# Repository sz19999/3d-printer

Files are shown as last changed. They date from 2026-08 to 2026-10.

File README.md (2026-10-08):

# EE Bachelor's Capstone Project - Cartesian 3D Printer

## Project Overview
This project involves the ground-up design and programming of a custom Cartesian 3D printer. Focuses on developing a hardware and software ecosystem — spanning from custom PCB design to a custom firmware.

## Core Objectives
*   **Mechanical Systems:** Design and assemble a rigid Cartesian frame optimized for precise XYZ axis motion control.
*   **Hardware Design:** Architect and route a custom mainboard Printed Circuit Board (PCB) from scratch, managing power distribution, stepper driver interfaces, and sensor inputs.
*   **Firmware Development:** Write dedicated, low-latency control firmware to handle G-code parsing, thermal regulation (PID loops), and precise motor acceleration profiles.

## Documents
*    **[HW & SW Architecture Diagram](./docs/assets/)** - Architectural block diagrams
*    **[PCB Schematics & Layout](./docs/)**

## Technical Stack & Tools
*   **Hardware / PCB Design:** Altium Designer
*   **Firmware Framework:** ESP-IDF, C

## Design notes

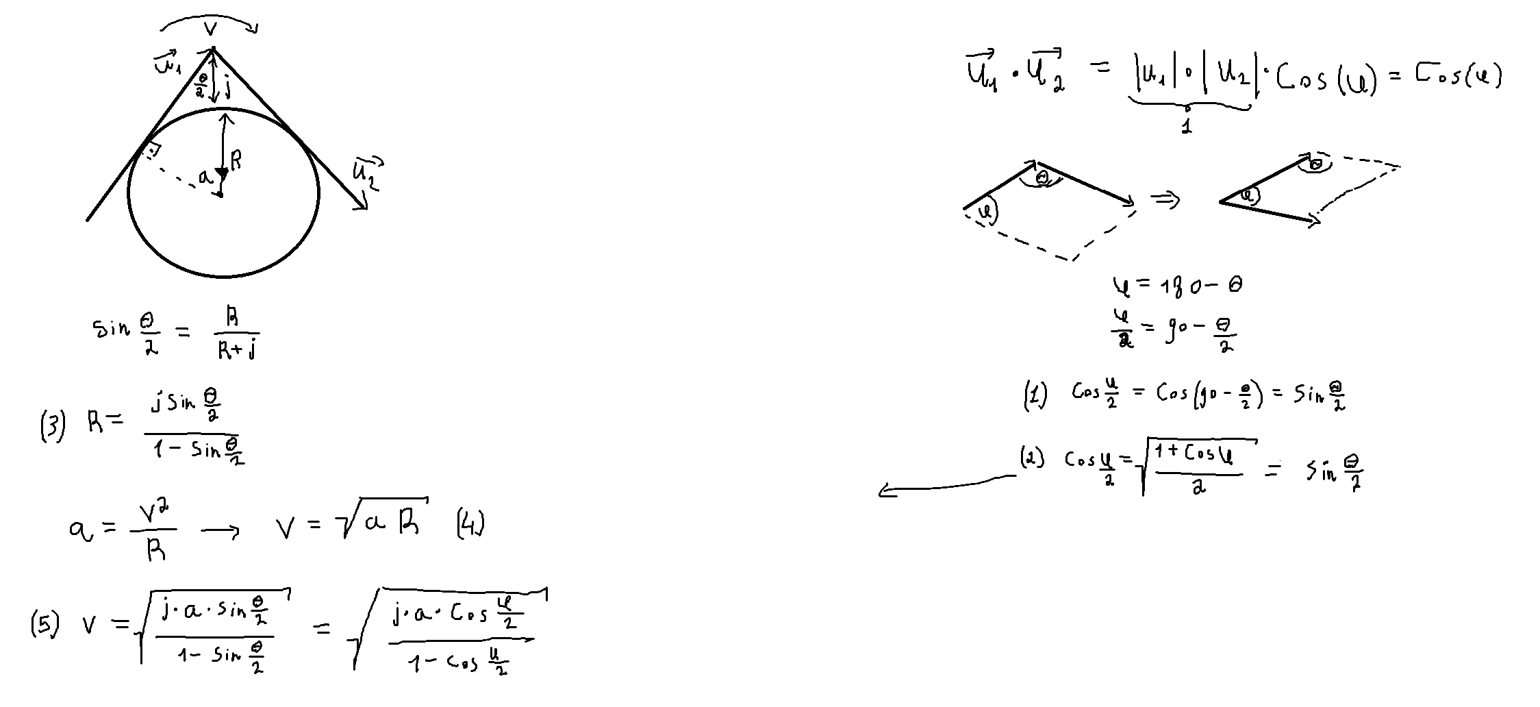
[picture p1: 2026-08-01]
docs/assets/junction_speed.png

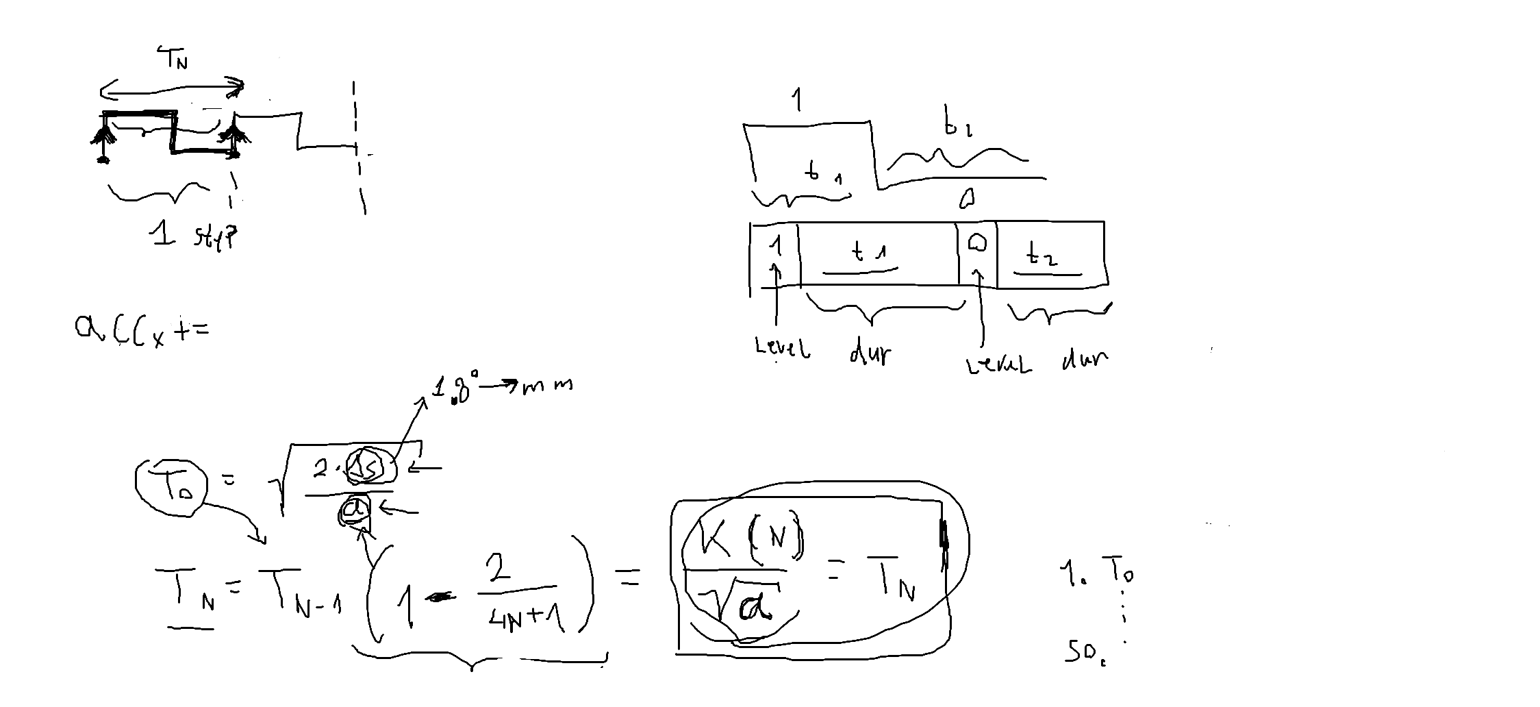
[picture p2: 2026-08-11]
docs/assets/cruise_speed.png

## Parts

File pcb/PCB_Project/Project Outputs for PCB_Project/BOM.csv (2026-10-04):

Line # | Name | Description | Designator | Quantity | SupplierPart | Supplier
 | sh-xh2.54-2p | Pins Structure:1x2P Pitch:2.5mm Mounting Type:Through Hole Number of Pins:2P Number of Rows:1 Number of PINs Per Row:2 Current Rating:3A Contact Material:Brass Contact Plating:Tin Operating Temperature:-25?~+85? Operating Temperature:-25?~+85? Voltage Rat | BED_ADC, BED_PWM, FAN, FAN_PWM, HEAD_ADC | 5 | C53261323 | LCSC
 | wj127-5.0-02p-14-00a | Number of Positions or Pins:1x2P Pitch:5mm Color:Green Mounting Type:Through Hole Number of Pins:2P Number of Rows:1 Number of PINs Per Row:2 Screw Specification:M2.5 Current Rating:15A Voltage Rating (Max):250V Wire Gauge - AWG:14~26 Wire Gauge - mm2:1.5 | BED_PWR, BTN_CN1, BTN_CN2, HEAD_PWR, PWR_DB1, PWR_DB2 | 6 | C3703 | LCSC
 | 100uF | Capacitance:100uF Tolerance:±20% Tolerance:±20% Voltage Rating:50V Ripple Current:146mA@120Hz Equivalent Series Resistance(ESR):- Diameter:8mm Height - Seated (Max):10.2mm Lifetime:2800hrs@105? Operating Temperature:-55?~+105? Operating Temperature:-55?~+ | C1, C2, C3, C4 | 4 | C970687 | LCSC
 | 100nF | Capacitance:100nF Tolerance:±10% Tolerance:±10% Voltage Rating:50V Temperature Coefficient:X7R | C5, C6, C7 | 3 | C1711 | LCSC
 | 22uF | Capacitance:22uF Tolerance:±20% Tolerance:±20% Voltage Rating:10V Temperature Coefficient:X5R | C8, C9, C10 | 3 | C29277 | LCSC
 | sh-xh2.54-4p | Pins Structure:1x4P Pitch:2.5mm Mounting Type:Through Hole Number of Pins:4P Number of Rows:1 Number of PINs Per Row:4 Current Rating:3A Contact Material:Brass Contact Plating:Tin Operating Temperature:-25?~+85? Operating Temperature:-25?~+85? Voltage Rat | CN2, CN3, CN4, CN5 | 4 | C53261325 | LCSC
 | s3mb-13-f | Diode Configuration:1 Independent Voltage - Forward(Vf@If):1.15V@3A Voltage - DC Reverse(Vr):1kV Current - Rectified:3A Reverse Leakage Current (Ir):10uA@1kV Non-Repetitive Peak Forward Surge Current:- Operating Junction Temperature Range:-65?~+150? Opera | D1 | 1 | C70426 | LCSC
 | wj127-5.0-04p-14-00a | Number of Positions or Pins:1x4P Pitch:5mm Color:Green Mounting Type:Through Hole Number of Pins:4P Number of Rows:1 Number of PINs Per Row:4 Screw Specification:M2.5 Current Rating:15A Voltage Rating (Max):250V Wire Gauge - AWG:14~26 Wire Gauge - mm2:1.5 | I2C_1, I2C_2 | 2 | C192779 | LCSC
 | 2.54-1*1p? | Pin Structure:1x1P Pitch:- Row Spacing:- Circluar Pins/Square Pins:Pin Header Mounting Type:Through Hole Number of Rows:1 Number of Pins:1P Current Rating:3A Voltage Rating (Max):- Length of Mating Pin:6mm Insulation Height:2.5mm Length of End Connection | J1, J2, J3, J4, J5, J6 | 6 | C81276 | LCSC
 | 2.54-1*3p? | Pin Structure:1x3P Pitch:2.54mm Row Spacing:- Circluar Pins/Square Pins:Pin Header Mounting Type:Through Hole Number of Rows:1 Number of Pins:3P Current Rating:3A Voltage Rating (Max):- Length of Mating Pin:6mm Insulation Height:2.5mm Length of End Connec | J7, J8, J9 | 3 | C49257 | LCSC
 | ncd0805r1_c84256 | Lamp Holder Type:- Illumination Color:Red Voltage - Forward(Vf):1.6V~2.6V Voltage - Forward(Vf):1.6V~2.6V Power(Watts):65mW Test Current:25mA Wavelength - Dominant:615nm~630nm Wavelength - Dominant:615nm~630nm Peak Wavelength:630nm Peak Wavelength:630nm D | LED1 | 1 | C84256 | LCSC
 | fh2.54-09-22pzd | Holes Structure:1x22P Pitch:2.54mm Circular Hole / Square Hole:Square Hole Mounting Type:Through Hole Number of Rows:1 Number of Positions:22P Current Rating:3A Holes Direction:Top Insulation Height:8.5mm Contact Material:Brass Contact Plating:Gold Operat | P1, P2 | 2 | C7500786 | LCSC
 | 2.54-1*8p??? | Holes Structure:1x8P Pitch:2.54mm Row Spacing:- Circular Hole / Square Hole:Square Hole Mounting Type:Through Hole Number of Rows:1 Number of Positions:8P Current Rating:3A Holes Direction:Top Insulation Height:8.5mm Contact Material:Brass Contact Plating | P3, P4, P5, P6, P8, P9, P10, P11 | 8 | C27438 | LCSC
 | 2.54-1*6p | Holes Structure:1x6P Pitch:2.54mm Row Spacing:- Circular Hole / Square Hole:Square Hole Mounting Type:Through Hole Number of Rows:1 Number of Positions:6P Current Rating:3A Voltage Rating (Max):- Holes Direction:Top Insulation Height:8.5mm Contact Materia | P7 | 1 | C40877 | LCSC
 | 2.54-1*4P |  | P18 | 1 | C2718488 | LCSC
 | dbt30s-7.62-2p-bk-p | Barrier Type:2-Side Pitch:7.62mm Number of Positions or Pins:1x2P Mounting Type:Straight Pin Location:Side Mount Number of Pins:2P Number of Rows:1 Number of PINs Per Row:2 Current Rating:15A Voltage Rating (Max):300V Wire Gauge - AWG:14~22 Wire Gauge - m | PWR1, PWR2 | 2 | C918082 | LCSC
 | ktc3265(range:160-320) | type:NPN Current - Collector(Ic):800mA Collector - Emitter Voltage VCEO:30V Pd - Power Dissipation:200mW DC Current Gain:160 DC Current Gain:160 Transition frequency(fT):120MHz Current - Collector Cutoff:100nA Vce Saturation(VCE(sat)):500mV Operating Temp | Q1, Q2 | 2 | C8531 | LCSC
 | 4.7k | Type:Thick Film Resistors Resistance:4.7kO Tolerance:±1% Tolerance:±1% Power(Watts): Overload Voltage (Max): Temperature Coefficient:±100ppm/? Temperature Coefficient:±100ppm/? Operating Temperature Range:-55?~+155? Operating Temperature Range:-55?~+155? | R1, R2, R3, R4, R5, R6, R9 | 7 | C17673 | LCSC
 | 1k | Type:Thick Film Resistors Resistance:1kO Tolerance:±1% Tolerance:±1% Power(Watts): Overload Voltage (Max): Temperature Coefficient:±100ppm/? Temperature Coefficient:±100ppm/? Operating Temperature Range:-55?~+155? Operating Temperature Range:-55?~+155? | R7, R8, R10, R11, R12 | 5 | C17513 | LCSC
 | 220 | Type:Thick Film Resistor Resistance:220O Tolerance:±1% Tolerance:±1% Power(Watts):125mW Voltage-Supply(Max):150V Temperature Coefficient:±100ppm/? Temperature Coefficient:±100ppm/? Operating Temperature:-55?~+155? Operating Temperature:-55?~+155? | R13 | 1 | C17557 | LCSC
 | ts6685h-250gf | Circuit:SPST Actuator Style:Round Button Operating Force:2.5N Mounting Type:Through Hole Length:6mm Width:6mm Switch Height:8.5mm Contact Current:50mA Voltage Rating:12V With Lamp:- Life:- | SW1 | 1 | C13828 | LCSC

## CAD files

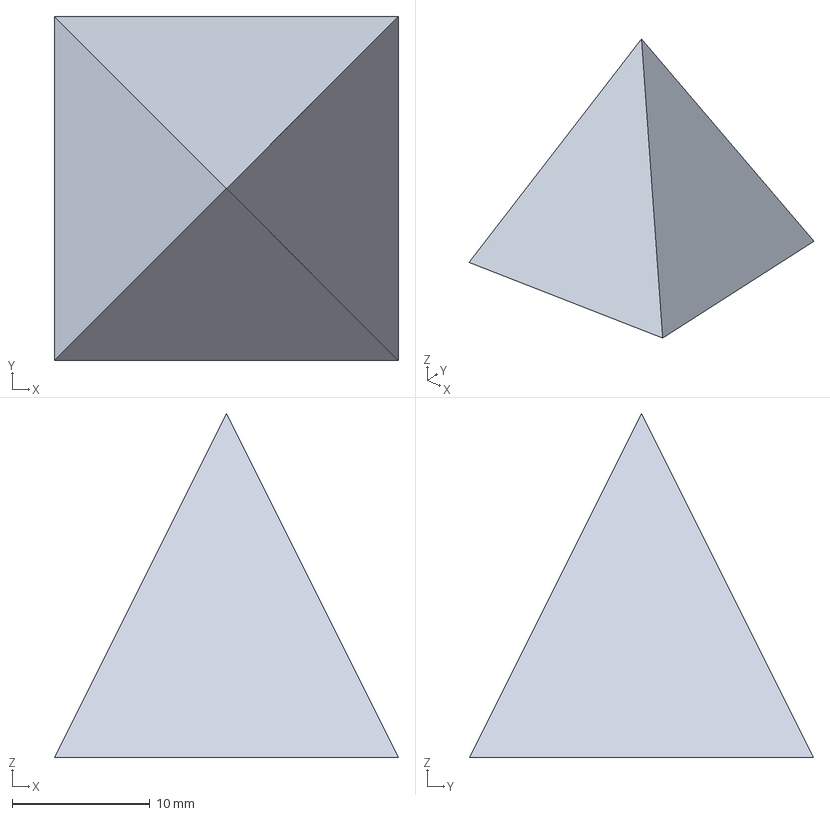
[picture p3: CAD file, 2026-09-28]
slicer/pyramid.3mf
25.0 x 25.0 x 25.0 mm

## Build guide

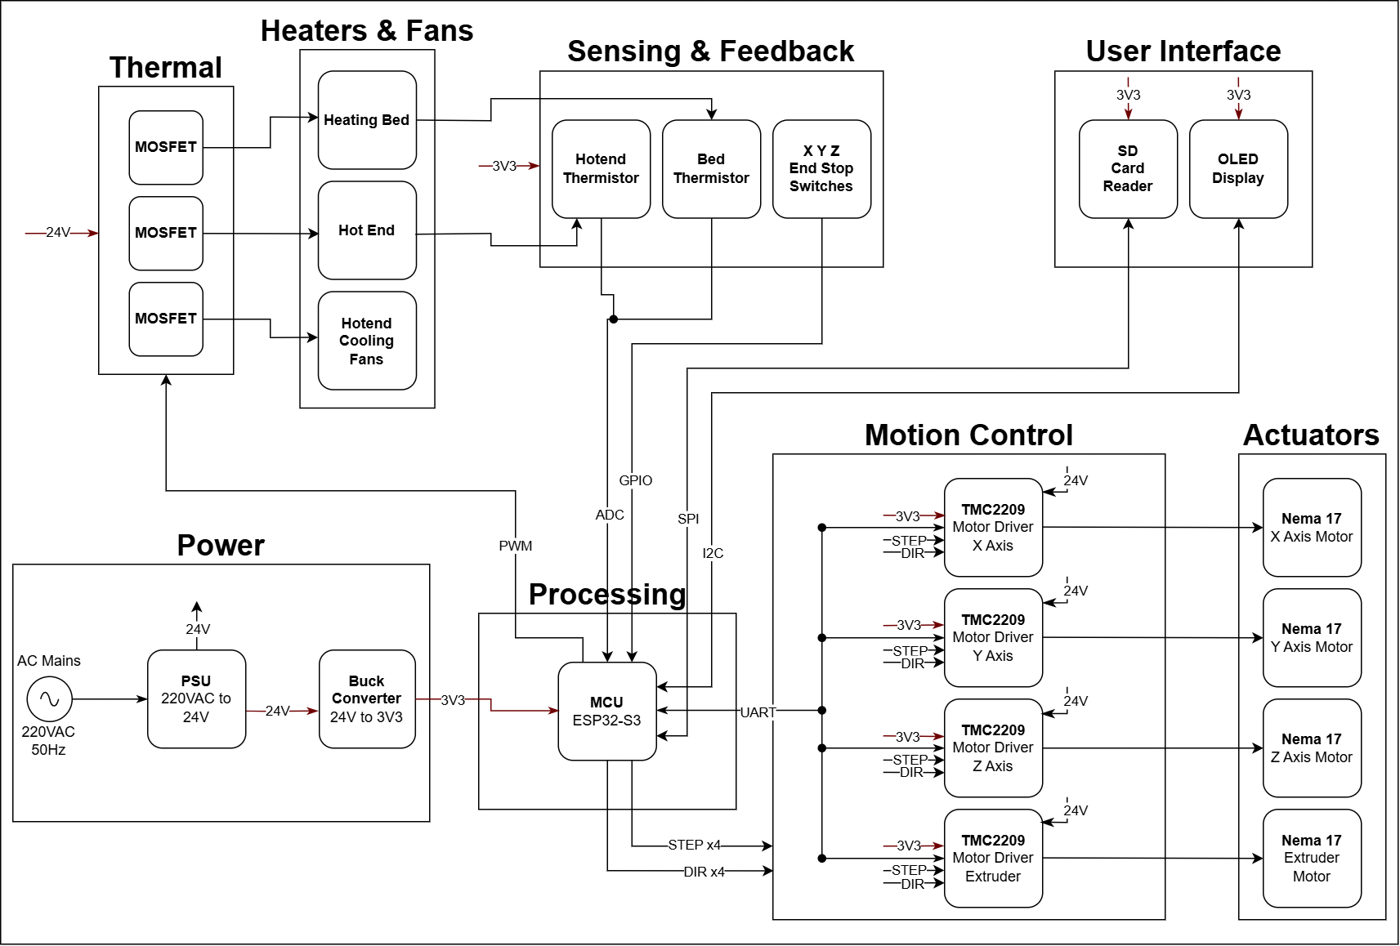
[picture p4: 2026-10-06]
docs/assets/3D Printer Hardware Architecture.drawio.png

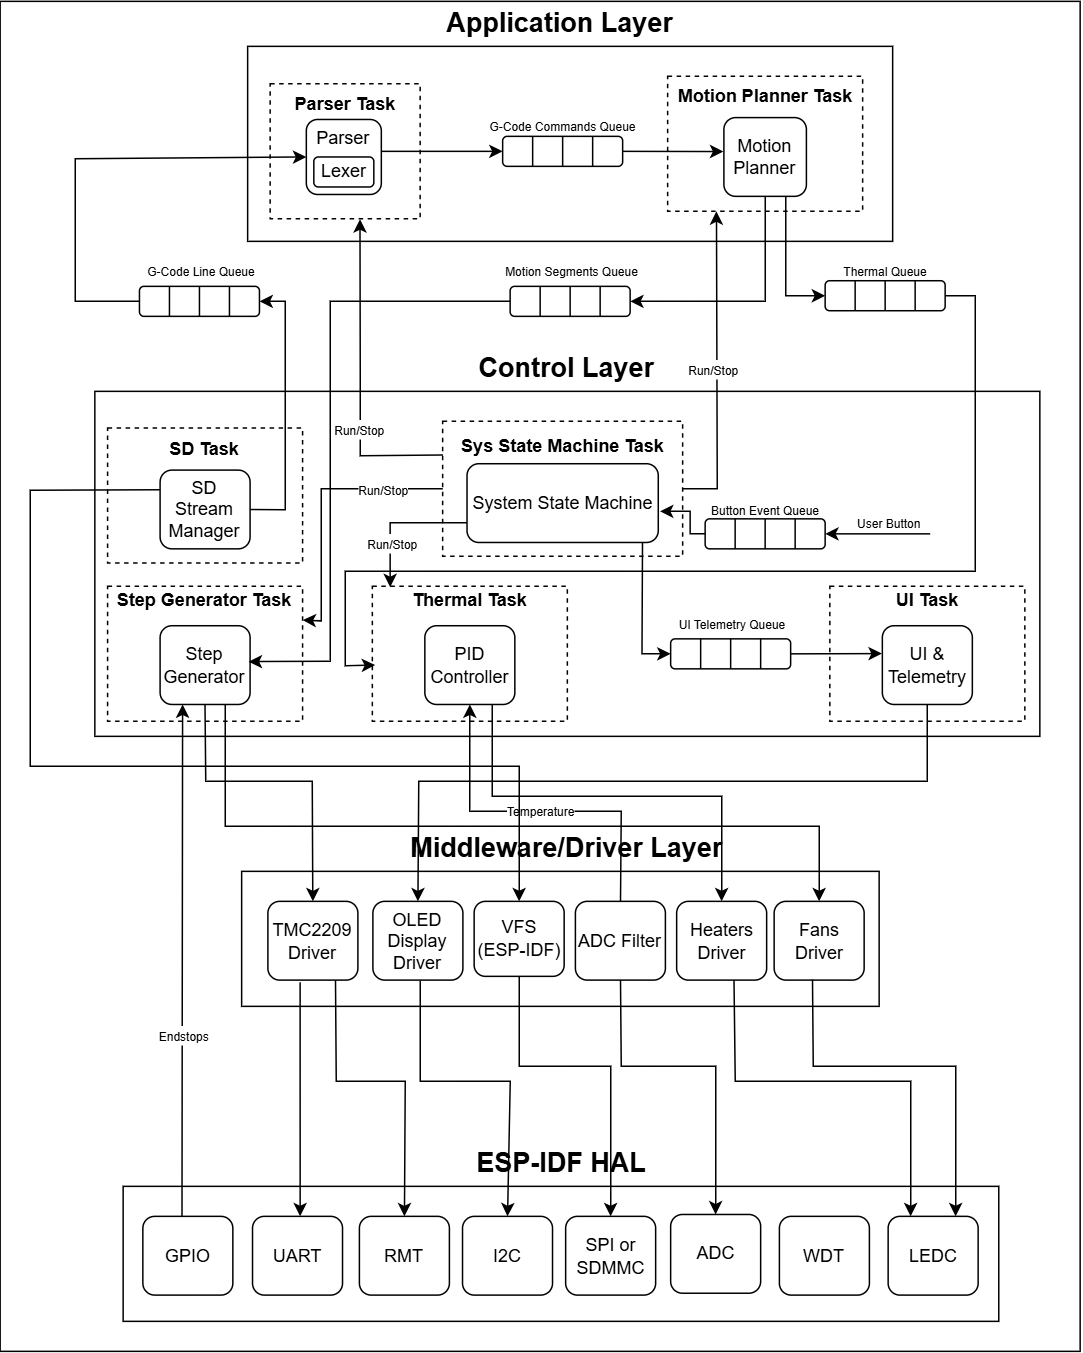
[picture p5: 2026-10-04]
docs/assets/3D Printer Software Architecture.drawio.png

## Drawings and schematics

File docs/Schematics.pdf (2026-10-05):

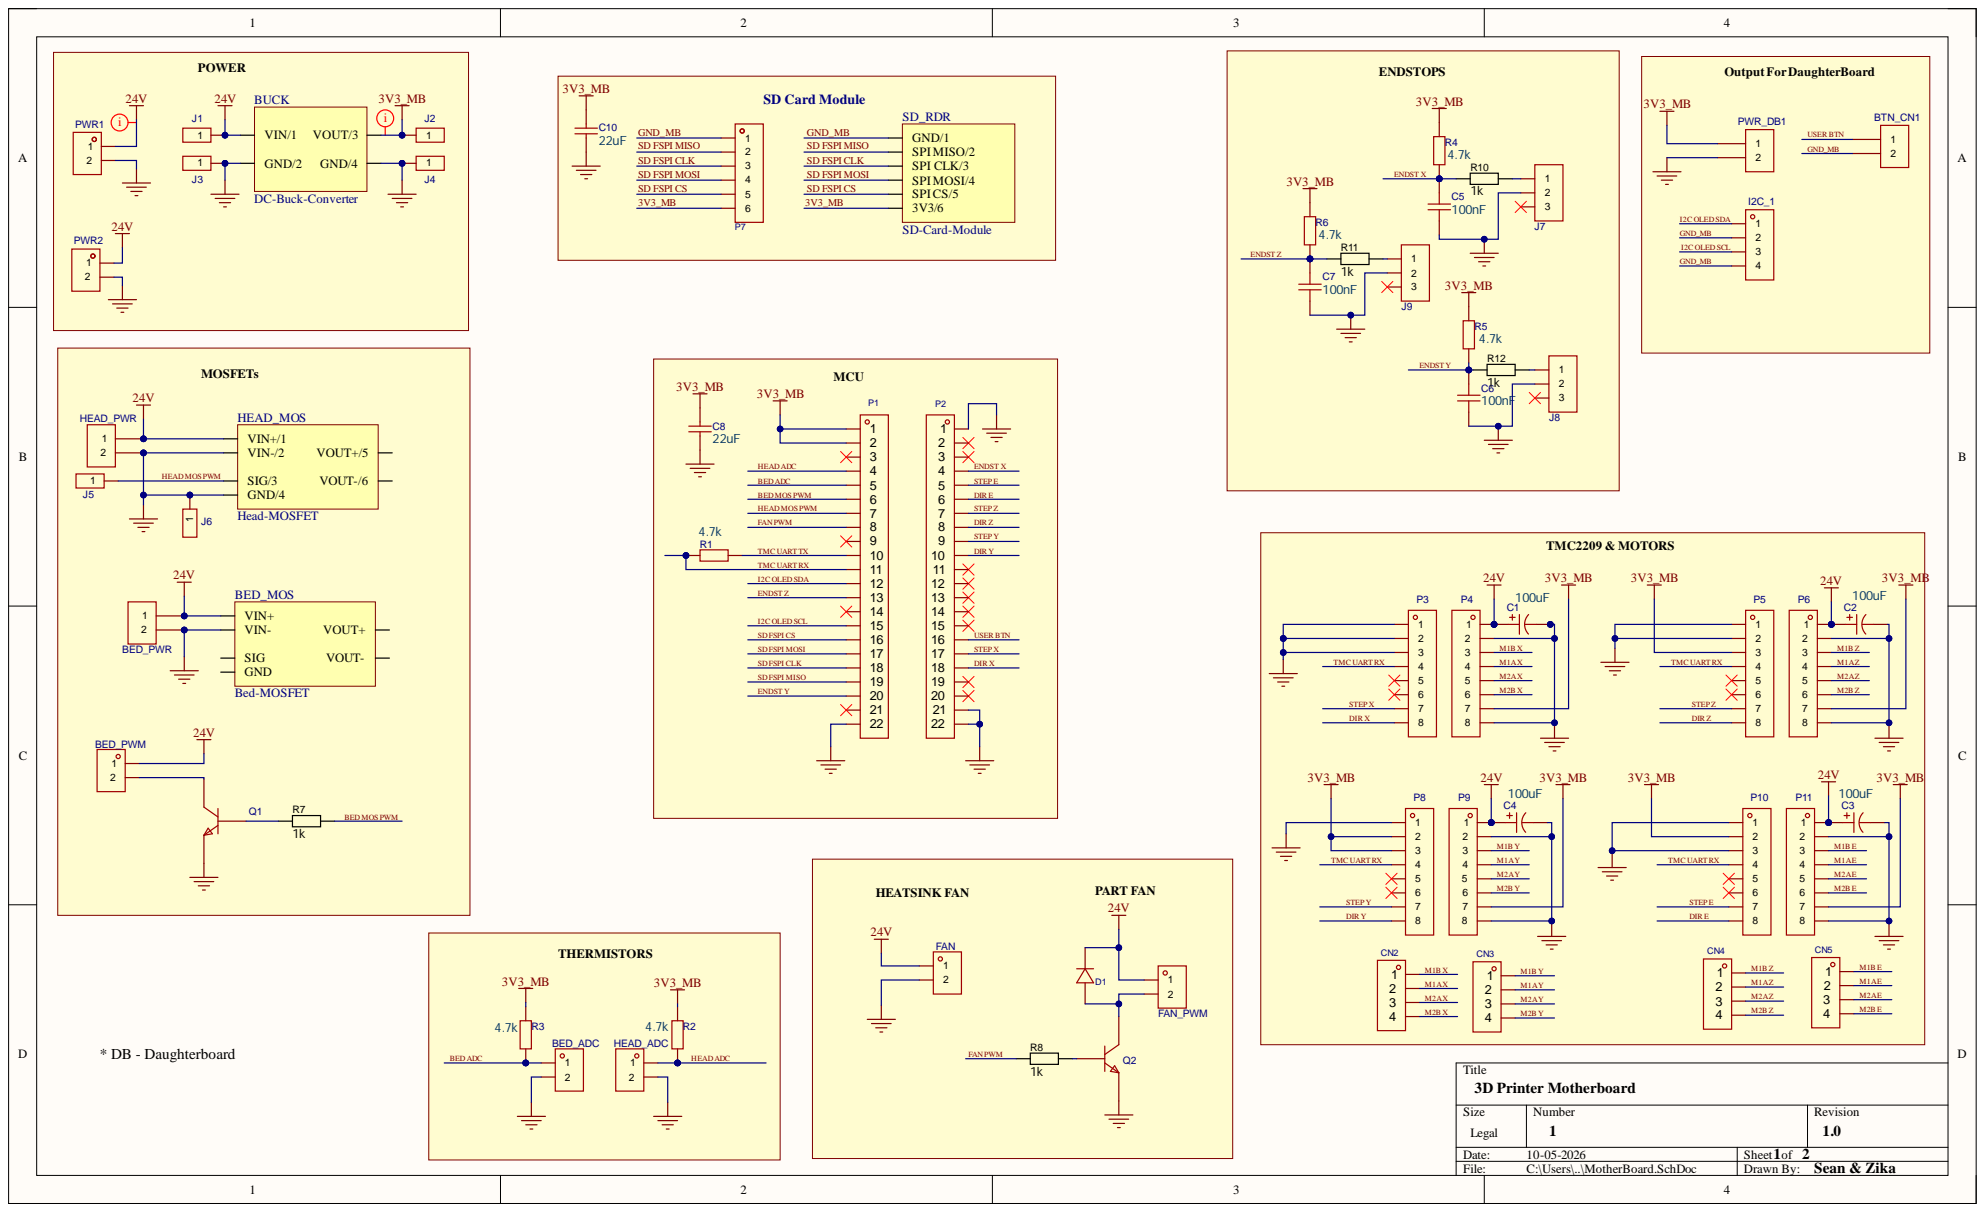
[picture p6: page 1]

Le g a l | mb e r 1 | Re visio n 1 . 0

Date : 1 0-0 5 -2 0 2 6 | S h e et 1 o f 2
File : C:\Users\. .\M oth erBo ard . S c h D o c | Drawn By : Sean & Zika

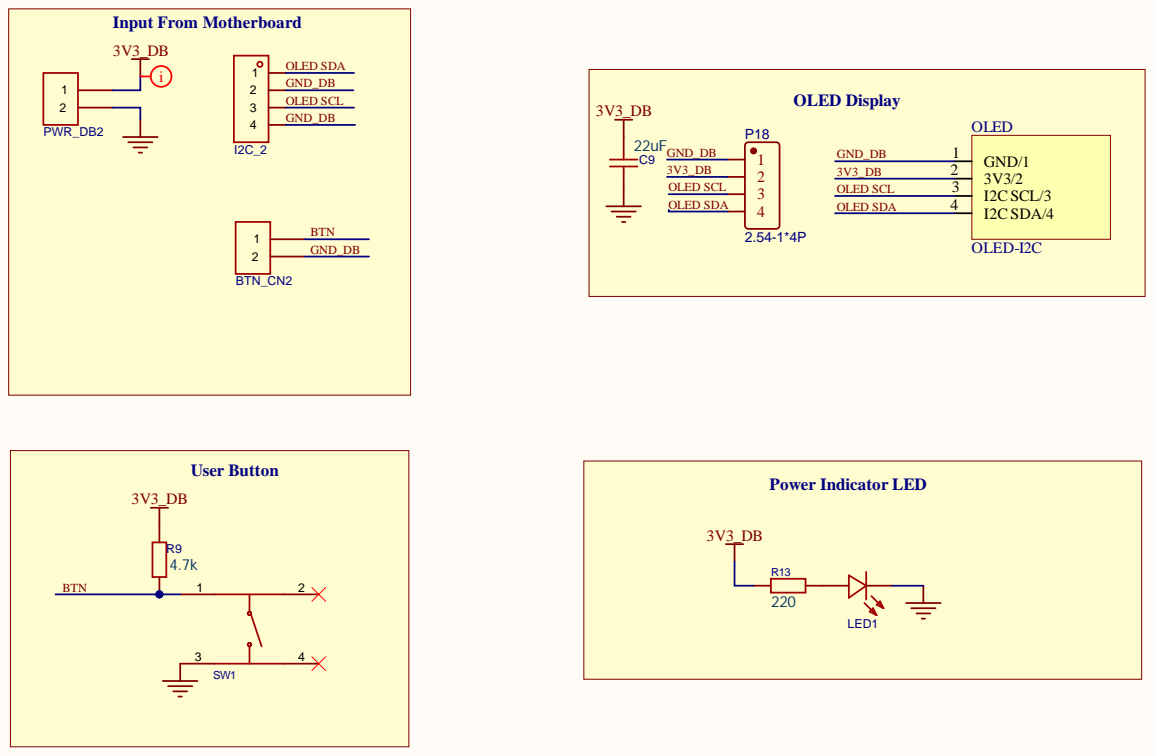
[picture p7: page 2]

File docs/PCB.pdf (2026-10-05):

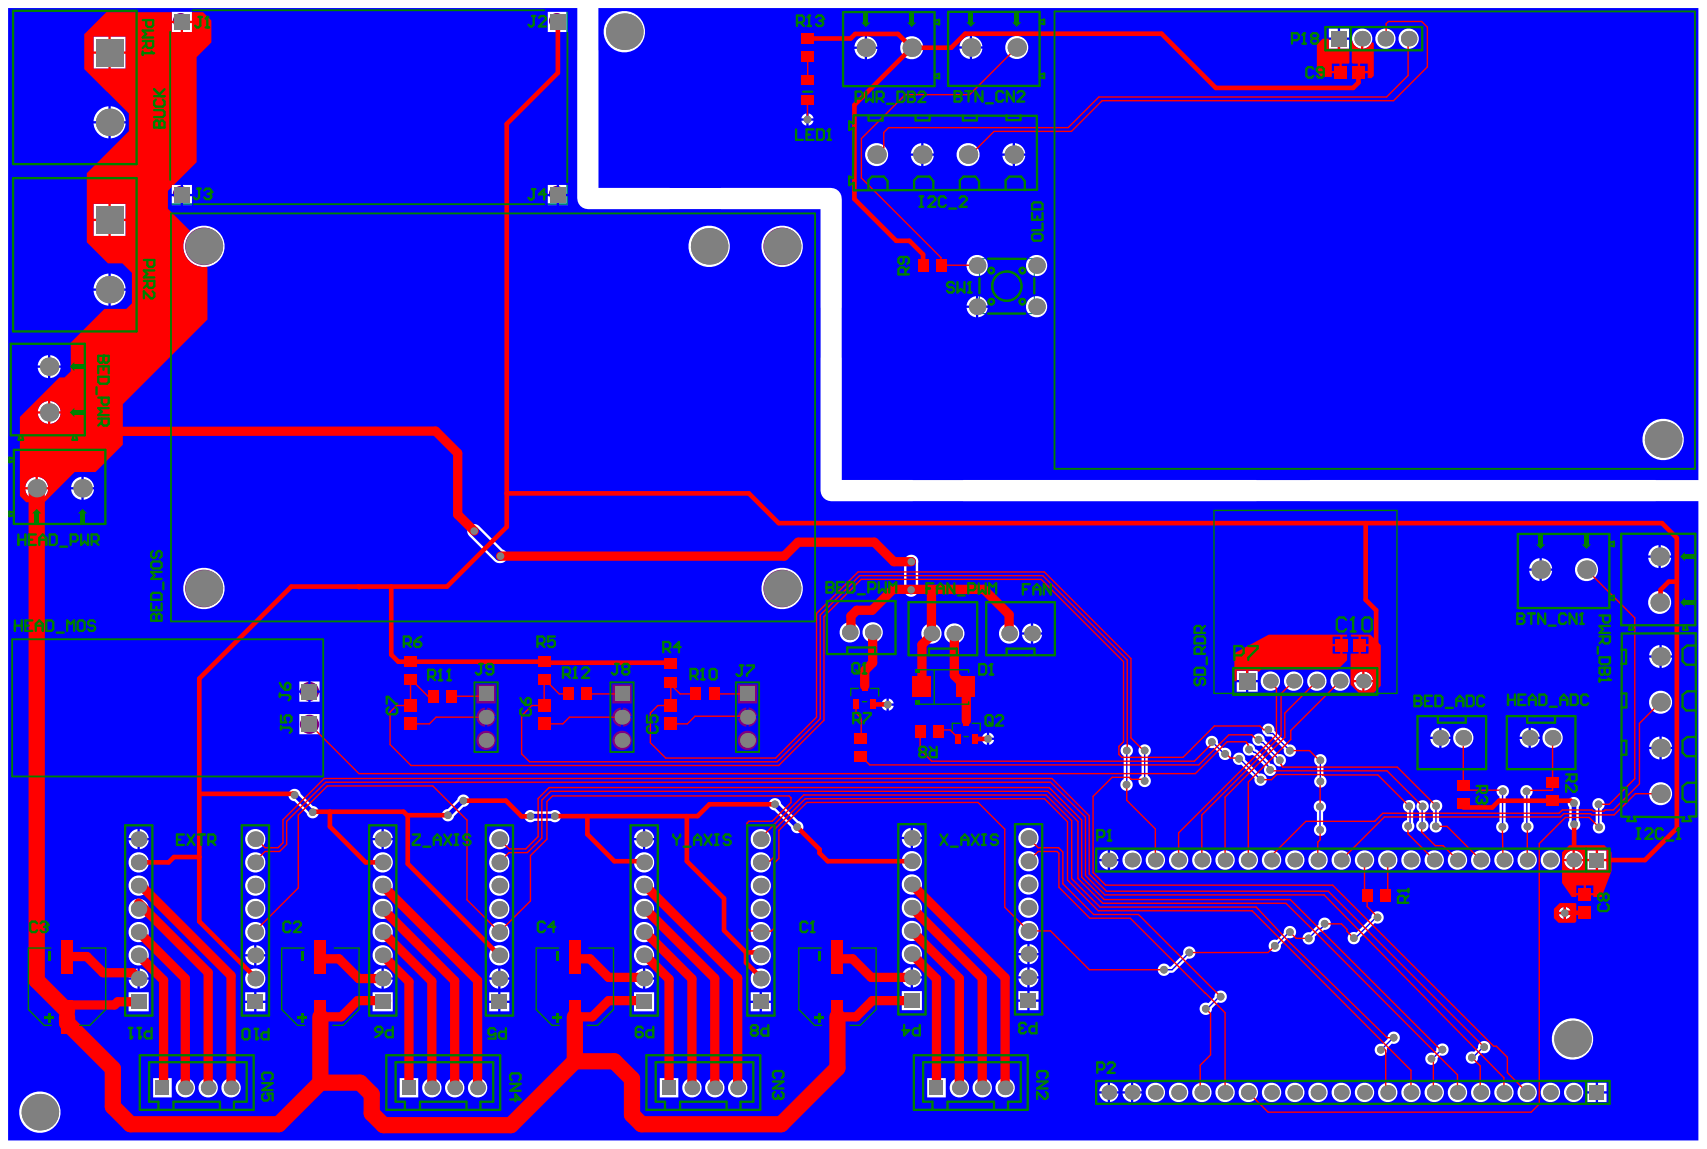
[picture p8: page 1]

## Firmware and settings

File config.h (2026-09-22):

#ifndef CONFIG_H
#define CONFIG_H

#define MICROSTEPS     16                    
#define PULLEY_TEETH   20                    
#define BELT_PITCH     2                     
#define STEP_ANGLE_DEG 1.8  
#define SCREW_LEAD     8
#define EFF_EX_GEAR_D  11   // need to verify the extruder gear diameter   
#define PI             3.14159265f

#define STEPS_PER_MM_BELT  (((360.0f  * MICROSTEPS) / (STEP_ANGLE_DEG * PULLEY_TEETH * BELT_PITCH)))
#define STEPS_PER_MM_SCREW (((360.0f  * MICROSTEPS) / (STEP_ANGLE_DEG * SCREW_LEAD)))
#define STEPS_PER_MM_GEAR  (((360.0f * MICROSTEPS) / (EFF_EX_GEAR_D * PI)))

#define MAX_VELOCITY_X  3500.0f / 60.0f  // 3500 mm/min
#define MAX_VELOCITY_Y  3500.0f / 60.0f
#define MAX_VELOCITY_Z  3500.0f / 60.0f
#define MAX_VELOCITY_E  3500.0f / 60.0f

#define MAX_ACCELERATION_X  500.0f // need to verify each acceleration constant and velocity
#define MAX_ACCELERATION_Y  500.0f
#define MAX_ACCELERATION_Z  100.0f
#define MAX_ACCELERATION_E  500.0f

#define JUNCTION_DEVIATION  0.02f // 0.02mm - need to test

#define MAX_DISTANCE_X 160.0f
#define MAX_DISTANCE_Y 160.0f
#define MAX_DISTANCE_Z 160.0f

#endif

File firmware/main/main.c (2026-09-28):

#include <stdio.h>
#include <dirent.h>
#include <string.h>
#include <math.h>

#include "freertos/FreeRTOS.h"
#include "freertos/task.h"
#include "freertos/queue.h"
#include "freertos/event_groups.h"
#include "esp_log.h"
#include "esp_rom_sys.h"
#include "driver/gpio.h"
#include "nvs_flash.h"

#include "gcode_parser.h"
#include "motion_planner.h"
#include "spi_sd.h"
#include "step_generator.h"
#include "sys_state_machine.h"
#include "thermal_task.h"
#include "user_interface.h"
#include "i2c_oled.h"
#include "tmc2209.h"


#define GCODE_LINE_MAX_LEN 128
#define SYS_RUNNING_BIT (1 << 0)

const char *TAG_PARSER  = "PARSER_TASK";
const char *TAG_PLANNER = "PLANNER_TASK";
const char *TAG_MAIN    = "MAIN_APP";
const char *TAG_MOTION  = "MOTION_BLOCK_TASK";
const char *TAG_SD      = "SD_STREAMER_TASK";
const char *TAG_RMT     = "STEP_GENERATOR_TASK";
const char *TAG_SYS     = "SYS_STATE_TASK";
const char *TAG_THERMAL = "THERMAL_TASK";
const char* TAG_UI   = "UI_TASK"; 

// Global handles for queues
QueueHandle_t gcode_line_queue = NULL;
QueueHandle_t gcode_cmds_queue = NULL;
QueueHandle_t motion_queue = NULL;
QueueHandle_t gpio_evt_queue = NULL;
QueueHandle_t thermal_cmds_queue = NULL;
QueueHandle_t ui_queue       = NULL;

TaskHandle_t xParserTaskHandle  = NULL;
TaskHandle_t xSDTaskHandle      = NULL;
TaskHandle_t xPlannerTaskHandle = NULL;
TaskHandle_t xStepGenTaskHandle = NULL;
TaskHandle_t xSysStateTaskHandle = NULL;
TaskHandle_t xThermalTaskHandle = NULL;
TaskHandle_t xUITaskHandle       = NULL;

EventGroupHandle_t sys_event_group;

// Live status for the OLED status screen. Each variable has exactly one writer
// task; the UI task only reads them. 32-bit loads/stores are atomic on the S3.
static volatile long  g_file_size        = 0;      // SD streamer
static volatile long  g_file_bytes_read  = 0;      // SD streamer
static volatile bool  g_file_done        = false;  // SD streamer
static volatile bool  g_waiting_for_heat = false;  // planner (inside M109/M190)
static volatile bool  g_block_executing  = false;  // step generator
static volatile bool  g_homing_block     = false;  // step generator
static volatile float g_pos_mm[3]        = {0};    // step generator: X/Y/Z after last finished block

void print_motion_block(const PlannedMotion* block);

#define SD_READ_RETRIES     5       // tries per line: card remounts after a read error before stopping the print
#define SD_RETRY_DELAY_MS   500

// End of the print for the streamer. One file per boot: park here for good
// (returning would make FreeRTOS abort and reboot the ESP32).
static void sd_park_forever(void) {
    g_file_done = true;
    while (1) {
        vTaskDelay(portMAX_DELAY);
    }
}

// Explicit case: a card read error mid-print (the card stops answering for a moment, e.g. from
// heater noise on its supply). FatFs keeps the error on the open file and the card may need a
// full re-init, so: close the file, remount the card, reopen the file and seek back to the start
// of the line that failed. The queued moves keep the printer busy meanwhile.
// Stops the print (heaters off) and parks the task if the line still can't be read.
static FILE* sd_recover_file(FILE* f, sdmmc_card_t** card, sdmmc_host_t* host, long line_start) {
    // Explicit case: the card remounts fine but the same spot fails again every time (e.g. a bad
    // sector). The tries are counted per line across calls; counting per call restarted at 1
    // after every successful remount and retried forever with the heaters on.
    static long s_failed_line = -1;
    static int  s_attempt     = 0;
    if (line_start != s_failed_line) {
        s_failed_line = line_start;
        s_attempt = 0;
    }

    fclose(f);

    while (s_attempt < SD_READ_RETRIES) {
        s_attempt++;
        ESP_LOGW(TAG_SD, "SD card read error at byte %ld - remounting the card (attempt %d of %d)",
                 line_start, s_attempt, SD_READ_RETRIES);

        if (*card != NULL) {
            esp_vfs_fat_sdcard_unmount(MOUNT_POINT, *card);
            spi_bus_free(host->slot);
            *card = NULL;
        }
        vTaskDelay(pdMS_TO_TICKS(SD_RETRY_DELAY_MS));

        sd_init(card, host);
        if (*card == NULL) {
            continue;
        }

        FILE* reopened = open_first_by_extension(MOUNT_POINT, ".gcode", "rb");
        if (reopened != NULL && fseek(reopened, line_start, SEEK_SET) == 0) {
            ESP_LOGI(TAG_SD, "SD card back - continuing from byte %ld", line_start);
            g_file_bytes_read = line_start;
            return reopened;
        }
        if (reopened != NULL) {
            fclose(reopened);
        }
    }

    ESP_LOGE(TAG_SD, "SD card READ ERROR at byte %ld of %ld - failed %d times, print stopped early! "
             "Re-copy the file or try another SD card.", line_start, (long)g_file_size, SD_READ_RETRIES);
    // Cancel the print like the missing-file case: with the running bit cleared the thermal task
    // turns both heaters off (otherwise the hot nozzle would sit on the print indefinitely).
    xEventGroupClearBits(sys_event_group, SYS_RUNNING_BIT);
    sd_park_forever();
    return NULL;
}

void sd_streamer_task(void *pvParameters) {
    ESP_LOGI(TAG_SD, "Task started successfully on core %d", xPortGetCoreID());

    sdmmc_card_t* card = NULL;
    sdmmc_host_t host  = SDSPI_HOST_DEFAULT();
    FILE* f = NULL;

    // Try again on every Start Print until a file opens. This task must never return
    // (FreeRTOS then aborts and the ESP32 reboots), so a missing card or file cancels
    // the print instead.
    while (f == NULL) {
        // block here until the bit is set.
        xEventGroupWaitBits(
            sys_event_group,
            SYS_RUNNING_BIT,
            pdFALSE,        // Don't clear bit on exit (so other tasks stay unblocked)
            pdTRUE,         // Wait for all bits
            portMAX_DELAY   // Wait indefinitely
        );

        // init & mount sd card
        card = NULL;
        sd_init(&card, &host);

        // find the first gcode file in the sd card
        f = open_first_by_extension(MOUNT_POINT, ".gcode", "rb");
        if (f == NULL) {
            ESP_LOGE(TAG_SD, "Couldn't open a .gcode file - print cancelled. Check the SD card and the file name.");
            if (card != NULL) {
                esp_vfs_fat_sdcard_unmount(MOUNT_POINT, card);
                spi_bus_free(host.slot);
            }
            xEventGroupClearBits(sys_event_group, SYS_RUNNING_BIT);
        }
    }

    {
        ESP_LOGI(TAG_SD, "Opened gcode file scuccessfuly!");

        // file size for the progress display
        if (fseek(f, 0, SEEK_END) == 0) {
            g_file_size = ftell(f);
            fseek(f, 0, SEEK_SET);
        }
        g_file_bytes_read = 0;
        g_file_done = false;

        while(1) {
            xEventGroupWaitBits(
                sys_event_group,
                SYS_RUNNING_BIT,
                pdFALSE,        // Don't clear bit on exit (so other tasks stay unblocked)
                pdTRUE,         // Wait for all bits
                portMAX_DELAY   // Wait indefinitely
            );

            char gcode_line[GCODE_LINE_MAX_LEN];
            long line_start = g_file_bytes_read;   // file offset of this line, to re-read it after a card error

            // read gcode line
            char* got = fgets(gcode_line, sizeof(gcode_line), f);

            // Explicit case: card read error. fgets can still return the first part of the line
            // (last time a lone "G"), so check ferror before using the line at all.
            if (ferror(f)) {
                f = sd_recover_file(f, &card, &host, line_start);
                continue;   // read this line again from its start
            }

            if (got == NULL) {
                ESP_LOGI(TAG_SD, "Reached to the end of the gcode file!");
                fclose(f);
                sd_park_forever();
            }

            size_t line_len = strlen(gcode_line);
            g_file_bytes_read += line_len;

            // Explicit case: a line longer than the buffer. PrusaSlicer's settings block at the
            // end of the file has lines like "; start_gcode = G28 ...\nG1 X60 E9 ..." that are
            // hundreds of chars. fgets returned only the start; drop the whole line, or the rest
            // would be read as separate lines and could run as real commands.
            if (line_len == sizeof(gcode_line) - 1 && gcode_line[line_len - 1] != '\n') {
                int c;
                long dropped = 0;
                while ((c = fgetc(f)) != EOF && c != '\n') {
                    dropped++;
                }
                if (ferror(f)) {
                    f = sd_recover_file(f, &card, &host, line_start);
                    continue;   // read this long line again from its start
                }
                g_file_bytes_read += dropped + (c == '\n' ? 1 : 0);

                if (dropped > 0) {
                    if (gcode_line[0] != ';') {
                        ESP_LOGW(TAG_SD, "Skipped a command line longer than %d chars: \"%.24s...\"",
                                 (int)sizeof(gcode_line) - 1, gcode_line);
                    }
                    continue;
                }
                // dropped == 0: the line was exactly buffer-sized and complete; keep it.
            }

            // dispatch gcode line
            if (xQueueSend(gcode_line_queue, gcode_line, portMAX_DELAY) == pdPASS) { // Wait indefinitely if queue is full
                ESP_LOGD(TAG_SD, "Dispatched gcode line to gcode_line_queue.");
            }
            vTaskDelay(1); 
           // vTaskDelay(pdMS_TO_TICKS(1000)); // Brief delay for smooth serial observation
        }

        // teardown & clean unmount
        esp_vfs_fat_sdcard_unmount(MOUNT_POINT, card);
    }
}

void parser_task(void *pvParameters) {
    char gcode_line[GCODE_LINE_MAX_LEN];
    GCodeCommand gcode_cmd;

    ESP_LOGI(TAG_PARSER, "Task started successfully on core %d", xPortGetCoreID());

    while (1) {
        xEventGroupWaitBits(
                sys_event_group,
                SYS_RUNNING_BIT,
                pdFALSE,        // Don't clear bit on exit (so other tasks stay unblocked)
                pdTRUE,         // Wait for all bits
                portMAX_DELAY   // Wait indefinitely
            );

        // Wait indefinitely for raw gcode string lines
        if (xQueueReceive(gcode_line_queue, gcode_line, portMAX_DELAY) == pdTRUE) {
            ESP_LOGD(TAG_PARSER, "Received raw line: \"%s\"", gcode_line);

            // Parse raw gcode line text buffer
            if (!parse_command(gcode_line, &gcode_cmd)) {
                // Expected for slicer lines we don't support (e.g. "M73 P5 R10"): skip them.
                ESP_LOGW(TAG_PARSER, "Skipped unsupported line: \"%s\"", gcode_line);
                continue;   // dont dispatch invalid commands
            }

            // dont dispatch lines without a command: comments and blank lines
            if (gcode_cmd.command_letter == '\0') continue;

            ESP_LOGD(TAG_PARSER, "Successfully parsed G-Code command: \"%s\".", gcode_line);

            // Dispatch into the parsed gcode queue
            if (xQueueSend(gcode_cmds_queue, &gcode_cmd, portMAX_DELAY) == pdPASS) {
                ESP_LOGD(TAG_PARSER, "Dispatched GCodeCommand to gcode_cmds_queue.");
            } else {
                ESP_LOGE(TAG_PARSER, "gcode_cmds_queue full! Command dropped.");
            }
        }
        vTaskDelay(1);
       // vTaskDelay(pdMS_TO_TICKS(1000)); // Brief delay for smooth serial observation
    }
}

// Send every block still held in the lookahead buffer to the step generator.
static void flush_planner_buffer(RingBuffer *buffer) {
    PlannedMotion *m;
    while ((m = front(buffer)) != NULL) {
        if (xQueueSend(motion_queue, m, portMAX_DELAY) == pdPASS) {
            print_motion_block(m);
            pop(buffer);
        }
    }
}

// Block until the heater reports "at target" for the command stamped `seq`.
// Returns early on a thermal fault or when the print is aborted.
static void planner_wait_for_temperature(heater_source_t heater, uint32_t seq) {
    const char *name = (heater == HEATER_BED) ? "BED" : "HOTEND";
    ESP_LOGI(TAG_PLANNER, "Waiting for %s to reach target...", name);

    g_waiting_for_heat = true;   // shown as HEATING on the display

    TickType_t last_log = xTaskGetTickCount();
    while (1) {
        if (thermal_fault_active()) {
            ESP_LOGE(TAG_PLANNER, "Stopped waiting for %s: thermal fault.", name);
            break;
        }
        if ((xEventGroupGetBits(sys_event_group) & SYS_RUNNING_BIT) == 0) {
            ESP_LOGW(TAG_PLANNER, "Stopped waiting for %s: print aborted.", name);
            break;
        }
        // Only trust "at target" once the thermal task has applied THIS command.
        if ((int32_t)(thermal_last_applied_seq() - seq) >= 0 && thermal_at_target(heater)) {
            ESP_LOGI(TAG_PLANNER, "%s at target (%.1f C). Resuming.", name, thermal_get_temp(heater));
            break;
        }
        if (xTaskGetTickCount() - last_log >= pdMS_TO_TICKS(5000)) {
            last_log = xTaskGetTickCount();
            ESP_LOGI(TAG_PLANNER, "...%s at %.1f C, still heating", name, thermal_get_temp(heater));
        }
        vTaskDelay(pdMS_TO_TICKS(200));
    }

    g_waiting_for_heat = false;
}

// Block until the M303 stamped `seq` has finished (complete, failed or faulted).
// Without this the G-code file would end and clearing the running bit would cancel the tune.
static void planner_wait_for_autotune(heater_source_t heater, uint32_t seq) {
    const char *name = (heater == HEATER_BED) ? "BED" : "HOTEND";
    ESP_LOGI(TAG_PLANNER, "Waiting for %s autotune to finish...", name);

    g_waiting_for_heat = true;   // shown as HEATING on the display

    TickType_t last_log = xTaskGetTickCount();
    while (1) {
        if (thermal_fault_active()) {
            ESP_LOGE(TAG_PLANNER, "Stopped waiting for %s autotune: thermal fault.", name);
            break;
        }
        if ((xEventGroupGetBits(sys_event_group) & SYS_RUNNING_BIT) == 0) {
            ESP_LOGW(TAG_PLANNER, "Stopped waiting for %s autotune: print aborted.", name);
            break;
        }
        // Only trust "not tuning" once the thermal task has applied THIS command.
        if ((int32_t)(thermal_last_applied_seq() - seq) >= 0 && !thermal_autotune_active(heater)) {
            ESP_LOGI(TAG_PLANNER, "%s autotune finished. Resuming.", name);
            break;
        }
        if (xTaskGetTickCount() - last_log >= pdMS_TO_TICKS(5000)) {
            last_log = xTaskGetTickCount();
            ESP_LOGI(TAG_PLANNER, "...%s autotune running, %.1f C", name, thermal_get_temp(heater));
        }
        vTaskDelay(pdMS_TO_TICKS(200));
    }

    g_waiting_for_heat = false;
}

// M400: block the G-code stream until every queued move has finished executing.
// Returns early on a thermal fault or when the print is aborted.
static void planner_wait_for_moves(RingBuffer *buffer) {
    flush_planner_buffer(buffer);

    // "Idle" must be seen twice, 20 ms apart: right after the step generator takes the
    // last block off the queue, the queue is empty but it has not yet set g_block_executing.
    int idle_checks = 0;
    while (idle_checks < 2) {
        if (thermal_fault_active()) break;
        if ((xEventGroupGetBits(sys_event_group) & SYS_RUNNING_BIT) == 0) break;

        if (uxQueueMessagesWaiting(motion_queue) == 0 && !g_block_executing) {
            idle_checks++;
        } else {
            idle_checks = 0;
        }
        vTaskDelay(pdMS_TO_TICKS(20));
    }
}

// Same effect as the UI's Abort, triggered by a latched thermal fault.
static void abort_print_on_thermal_fault(RingBuffer *buffer) {
    ESP_LOGE(TAG_PLANNER, "THERMAL FAULT - aborting print.");
    xEventGroupClearBits(sys_event_group, SYS_RUNNING_BIT);
    vTaskSuspend(xStepGenTaskHandle);
    xQueueReset(gcode_line_queue);
    xQueueReset(gcode_cmds_queue);
    xQueueReset(motion_queue);
    xQueueReset(thermal_cmds_queue);
    init_buffer(buffer);
}
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
void app_main(void) {
    // FIRST: drive heater/fan MOSFET gates to a defined 0% duty. Until this runs
    // the pins float, and a floating gate can partly switch a heater on.
    mosfet_driver_init();

    // NVS holds the autotuned PID gains; the thermal task reads them at startup.
    esp_err_t nvs_err = nvs_flash_init();
    if (nvs_err == ESP_ERR_NVS_NO_FREE_PAGES || nvs_err == ESP_ERR_NVS_NEW_VERSION_FOUND) {
        // Partition is full or from an incompatible IDF version: wipe it (gains fall back to defaults).
        ESP_LOGW(TAG_MAIN, "NVS partition unusable (%s), erasing it.", esp_err_to_name(nvs_err));
        nvs_flash_erase();
        nvs_err = nvs_flash_init();
    }
    if (nvs_err != ESP_OK) {
        ESP_LOGE(TAG_MAIN, "NVS init failed (%s): PID gains will use built-in defaults.",
                 esp_err_to_name(nvs_err));
    }

    ESP_LOGI(TAG_MAIN, "Initializing IPC queues...");

    sys_event_group = xEventGroupCreate();

    motion_queue     = xQueueCreate(16, sizeof(PlannedMotion));
    gcode_cmds_queue = xQueueCreate(2, sizeof(GCodeCommand));
    gcode_line_queue = xQueueCreate(2, GCODE_LINE_MAX_LEN);
    thermal_cmds_queue = xQueueCreate(THERMAL_CMD_QUEUE_LEN, sizeof(thermal_cmd_t));
    ui_queue = xQueueCreate(5, sizeof(ui_data_t));
    gpio_evt_queue = xQueueCreate(10, sizeof(ButtonEdge_t));
    
    if (!motion_queue || !gcode_cmds_queue || !gcode_line_queue || !thermal_cmds_queue) {
        ESP_LOGE(TAG_MAIN, "Failed to allocate FreeRTOS Queues!");
        return;
    }

    ESP_LOGI(TAG_MAIN, "Spawning FreeRTOS tasks...");

    xTaskCreatePinnedToCore(parser_task, "Parser_Task", 4096, NULL, 2, &xParserTaskHandle, 0);
    // 8 KB: the 16-block lookahead RingBuffer lives on this stack (~1.8 KB), and homing
    // plus print_motion_block() format floats with sprintf/ESP_LOG. 4 KB overflowed on G28.
    xTaskCreatePinnedToCore(motion_planner_task, "Planner_Task", 8192, NULL, 2, &xPlannerTaskHandle, 0);
    xTaskCreatePinnedToCore(step_generator_task, "Step_Generator_Task", 4096, NULL, 2, &xStepGenTaskHandle, 1);
    xTaskCreatePinnedToCore(sd_streamer_task, "SD_Streamer_Task", 4096, NULL, 2, &xSDTaskHandle, 0);
    xTaskCreatePinnedToCore(sys_state_machine_task, "Sys_State_Machine_Task", 4096, NULL, 2, &xSysStateTaskHandle, 0);
    // Extra stack for the NVS flash calls (PID gains load at start, save after autotune).
    xTaskCreatePinnedToCore(thermal_task, "Thermal_Task", 6144, NULL, 3, &xThermalTaskHandle, 0);
    xTaskCreatePinnedToCore(ui_task, "UI_Task", 4096, NULL, 2, &xUITaskHandle, 0);

    ESP_LOGI(TAG_MAIN, "Initialization complete. Scheduler running.");
}

void print_motion_block(const PlannedMotion* block) {
    if (block == NULL) {
        ESP_LOGE(TAG_MOTION, "Cannot print NULL motion block.");
        return;
    }

    ESP_LOGD(TAG_MOTION, "=== Planned Motion Block Details ===");

    // Geometry & Distances
    ESP_LOGD(TAG_MOTION, "Path Length: %.2f mm | Total Vector Len: %.2f",
             block->path_length_mm, block->total_vector_length);
    ESP_LOGD(TAG_MOTION, "Unit Vector (X,Y,Z,E): (%.2f, %.2f, %.2f, %.2f)", 
             block->unit_vec[0], block->unit_vec[1], block->unit_vec[2], block->unit_vec[3]);

    // Velocities & Accelerations
    ESP_LOGD(TAG_MOTION, "Velocities - Entry: %.2f | Cruise: %.2f | Exit: %.2f", 
             block->v_entry, block->v_cruise, block->v_exit);
    ESP_LOGD(TAG_MOTION, "Max Accel - Path: %.2f | Vector: %.2f", 
             block->max_path_acceleration, block->max_vector_acceleration);

    // Axis Mapping & Steps
    ESP_LOGD(TAG_MOTION, "Master Axis: %d | Master Steps: %d  | Master Steps/mm: %.2f", 
             block->master_axis, block->master_steps, block->master_steps_per_mm);
    ESP_LOGD(TAG_MOTION, "Dir Bits: 0x%02X", block->dir_bits);
    ESP_LOGD(TAG_MOTION, "Axis Steps (X,Y,Z,E): (%d, %d, %d, %d)", block->steps[0], block->steps[1], 
            block->steps[2], block->steps[3]);

    // Trapezoidal Phase Step Counts
    ESP_LOGD(TAG_MOTION, "Phases - Accel Steps: %d | Cruise Steps: %d | Decel Steps: %d", 
            block->accel_steps, block->cruise_steps, block->decel_steps);
}

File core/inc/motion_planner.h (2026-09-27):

#ifndef MOTION_PLANNER_H
#define MOTION_PLANNER_H

#include <stdbool.h>
#include <stdint.h>

#include "gcode_parser.h"

#define NUM_AXES    4         // X, Y, Z, E
#define BUFFER_SIZE 16        // ring buffer size
#define MIN_PLANNER_BLOCKS 3  // min amount of blocks to start dispatching from ring buffer
#define MIN_STEP_MM 0.005f    // min step allowed

typedef enum {
    PLANNER_STATE_BUFFERING, // filling lookahead buffer; do not dispatch yet
    PLANNER_STATE_RUNNING    // active execution; stream blocks to step generator
} PlannerState;

typedef enum {
    MOTION_MODE_PRINTING, // Coordinated multi-axis moves (G1/G2/G3)
    MOTION_MODE_HOMING    // Single-axis homing routines (G28)
} motion_mode_t;

// motion block consumed by the Step Generator task
typedef struct {
    // motion planner parameters:
    float path_length_mm;           // total Cartesian path length (mm)
    float total_vector_length;      
    float unit_vec[NUM_AXES];       // direction unit vector (ux, uy, uz, ue)
    float cartesian_unit_vec[NUM_AXES - 1];
    
    float v_cruise;                 // desired cruise velocity (mm/s)
    float v_entry;                  // entry velocity from junction planner (mm/s)
    float v_exit;                   // exit velocity for next block (mm/s)
    
    float max_path_acceleration;    // max path acceleration allowed for this move 
    float max_vector_acceleration;  
    
    // pre-calculated step generator parameters:
    uint8_t dir_bits;           // dir_bits = [x_dir, y_dir, z_dir, e_dir, -]
    uint8_t master_axis;        // axis with the most steps 
    uint32_t steps[NUM_AXES];   // number of steps of each axis -> steps[] = [x_steps, y_steps, z_steps, e_steps]
    uint32_t master_steps;
    float master_steps_per_mm;  // velocity scale factor: (master_steps / path_length_mm)

    uint32_t accel_steps;       // how much steps to accelerate
    uint32_t decel_steps;
    uint32_t cruise_steps;

    motion_mode_t motion_mode;  // printing/homing

    float end_mm[3];            // X, Y, Z position (mm) once this block completes (for the display)
} PlannedMotion;

typedef struct 
{
    int32_t x, y, z, e;
} PointSteps;

typedef struct 
{
    float x, y, z, e;
} PointMM;

typedef struct {
    PlannedMotion arr[BUFFER_SIZE];  // a buffer which holds the motion profiles
    uint8_t tail;   // points on the oldest block
    uint8_t head;   // points on the next empty block space
    uint8_t count;  // holds the number of occupied slots in the buffer
} RingBuffer;

// metadata
typedef struct {
    uint32_t cmd_num;
    uint16_t temp_target;    // in celsius
    uint16_t fan_speed;
    bool     autotune_bed;   // M303 only: E-1 selects the bed, anything else the hotend
    uint32_t seq;            // stamped by the planner; the thermal task publishes the last applied seq
} thermal_cmd_t;

// main motion planner functions
bool is_motion_command(GCodeCommand* gcode_cmd);
void handle_motion_command(GCodeCommand* gcode_cmd, RingBuffer* buffer, PointMM*, PointSteps*, bool*);
void handle_metadata_command(GCodeCommand* gcode_cmd, thermal_cmd_t* metadata);

void create_initial_profile(GCodeCommand* gcode_cmd, PlannedMotion* motion, PointMM*, PointSteps*, bool);
void compute_junction_velocity(RingBuffer* buffer);
void backward_pass(RingBuffer* buffer);
void forward_pass(RingBuffer* buffer);
void recalculate_cruise_speed(RingBuffer* buffer);
void finalize_motion_profiles(RingBuffer* buffer);

// handle_motion_command() auxiliary functions
void plan_motion_segment(GCodeCommand* gcode_cmd, RingBuffer* buffer, PointMM*, PointSteps*, bool);
void set_axes_pos(GCodeCommand* gcode_cmd, PointMM* current_mm, PointSteps* current_steps, bool);
void home_axes(RingBuffer* buffer, PointMM* current_mm, PointSteps* current_steps, bool absolute_mode);
void set_motion_type(GCodeCommand* gcode_cmd, RingBuffer* buffer);

// handle_metadata_command() aux funcs
void set_heater_temp(GCodeCommand* gcode_cmd, thermal_cmd_t* metadata);
void set_fan_speed(GCodeCommand* gcode_cmd, thermal_cmd_t* metadata);
void set_autotune(GCodeCommand* gcode_cmd, thermal_cmd_t* metadata);

// create_initial_profile() helper functions
float limit_velocity(float v_target, float ux, float uy, float uz);
void compute_unit_vectors(PlannedMotion* motion, float deltas_mm[]);
void compute_path_and_vector_lengths(PlannedMotion* motion, float deltas_mm[]);
void compute_max_path_and_vector_acceleration(PlannedMotion* motion);
void compute_profile_velocities(GCodeCommand* gcode_cmd, PlannedMotion* motion, float* v_target_mm_s);
void update_target_coordinate(GCodeCommand* gcode_cmd, PointMM* target_mm, bool absolute_mode);
void clamp_target_to_axis_limits(PointMM* target_mm);
void compute_steps(PlannedMotion* motion, PointSteps* target_steps, PointSteps* current_steps);
void convert_from_mm_to_steps(PointSteps* target_steps, PointMM* target_mm);
void evaluate_step_directions(PlannedMotion* motion, PointSteps* current_steps, PointSteps* target_steps);
void compute_deltas_mm(float deltas_mm[], PointMM* target_mm, PointMM* current_mm);
float compute_cartesian_length(float deltas_mm[]);
void compute_path_and_vector_lengths(PlannedMotion*motion, float deltas_mm[]);
void compute_master_axis_steps(PlannedMotion* motion);
void compute_master_axis_steps_per_mm(PlannedMotion* motion);

// ring buffer API
void init_buffer(RingBuffer* buffer);
bool is_empty(const RingBuffer* buffer);
bool is_full(const RingBuffer* buffer);
bool append(RingBuffer* buffer, const PlannedMotion* motion);
void pop(RingBuffer* buffer);
PlannedMotion* front(RingBuffer* buffer);
uint8_t count(const RingBuffer* buffer);



#endif

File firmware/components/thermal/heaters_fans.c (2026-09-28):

#include "heaters_fans.h"
#include "driver/ledc.h"
#include "esp_log.h"

static const char *TAG = "MOSFET_DRIVER";

#define MAX_DUTY_VALUE ((1 << PWM_RES_BITS) - 1) // 1023

typedef struct {
    gpio_num_t gpio_num;
    ledc_channel_t channel;
    ledc_timer_t timer;
    bool invert; // true when the MOSFET is driven through an inverting stage (e.g. NPN pulling the gate low)
    const char *name;
} mosfet_config_t;

static const mosfet_config_t g_mosfet_map[PWM_CH_NUM] = {
    [PWM_CHANNEL_HOTEND] = { .gpio_num = HOTEND_GPIO,  .channel = LEDC_CHANNEL_0, .timer = LEDC_TIMER_0, .invert = false, .name = "Hotend"  },
    [PWM_CHANNEL_HEATBED] = { .gpio_num = HEATBED_GPIO, .channel = LEDC_CHANNEL_1, .timer = LEDC_TIMER_0, .invert = HEATBED_INVERTED, .name = "Heatbed" },
    [PWM_CHANNEL_PART_FAN] = { .gpio_num = PART_FAN_GPIO, .channel = LEDC_CHANNEL_2, .timer = LEDC_TIMER_1, .invert = PART_FAN_INVERTED, .name = "PartFan"     }
};

void mosfet_driver_init(void) {
    ESP_LOGI(TAG, "Initializing MOSFET PWM drivers...");

    // 1. Configure Timer 0 (Heaters: 100 Hz)
    ledc_timer_config_t heater_timer = {
        .speed_mode       = LEDC_LOW_SPEED_MODE,
        .timer_num        = LEDC_TIMER_0,
        .duty_resolution  = PWM_RESOLUTION,
        .freq_hz          = HEATER_PWM_FREQ_HZ,
        .clk_cfg          = LEDC_AUTO_CLK
    };
    if (ledc_timer_config(&heater_timer) != ESP_OK) {
        ESP_LOGE(TAG, "Failed to configure Heater PWM Timer!");
        return;
    }

    // 2. Configure Timer 1 (Fan: FAN_PWM_FREQ_HZ)
    ledc_timer_config_t fan_timer = {
        .speed_mode       = LEDC_LOW_SPEED_MODE,
        .timer_num        = LEDC_TIMER_1,
        .duty_resolution  = PWM_RESOLUTION,
        .freq_hz          = FAN_PWM_FREQ_HZ,
        .clk_cfg          = LEDC_AUTO_CLK
    };
    if (ledc_timer_config(&fan_timer) != ESP_OK) {
        ESP_LOGE(TAG, "Failed to configure Fan PWM Timer!");
        return;
    }

    // 3. Configure LEDC Channels
    for (int i = 0; i < PWM_CH_NUM; i++) {
        ledc_channel_config_t ledc_channel = {
            .speed_mode     = LEDC_LOW_SPEED_MODE,
            .channel        = g_mosfet_map[i].channel,
            .timer_sel      = g_mosfet_map[i].timer,
            .intr_type      = LEDC_INTR_DISABLE,
            .gpio_num       = g_mosfet_map[i].gpio_num,
            .duty           = 0, // Ensure output starts OFF
            .hpoint         = 0,
            .flags.output_invert = g_mosfet_map[i].invert // hardware inversion: duty 0 still means OFF
        };
        
        if (ledc_channel_config(&ledc_channel) != ESP_OK) {
            ESP_LOGE(TAG, "Failed to configure LEDC channel for %s (GPIO %d)", 
                     g_mosfet_map[i].name, g_mosfet_map[i].gpio_num);
        } else {
            ESP_LOGI(TAG, "%s channel initialized on GPIO %d", 
                     g_mosfet_map[i].name, g_mosfet_map[i].gpio_num);
        }
    }
}

void mosfet_set_duty_raw(pwm_channel_t chan, uint32_t duty) {
    if (chan >= PWM_CH_NUM) {
        ESP_LOGE(TAG, "Invalid channel index: %d", chan);
        return;
    }

    if (duty > MAX_DUTY_VALUE) {
        ESP_LOGW(TAG, "%s duty raw value %lu exceeds max (%d). Clamping to max.", 
                 g_mosfet_map[chan].name, (unsigned long)duty, MAX_DUTY_VALUE);
        duty = MAX_DUTY_VALUE;
    }

    ledc_channel_t ledc_chan = g_mosfet_map[chan].channel;
    
    if (ledc_set_duty(LEDC_LOW_SPEED_MODE, ledc_chan, duty) != ESP_OK) {
        ESP_LOGE(TAG, "Failed to set duty for %s", g_mosfet_map[chan].name);
        return;
    }

    if (ledc_update_duty(LEDC_LOW_SPEED_MODE, ledc_chan) != ESP_OK) {
        ESP_LOGE(TAG, "Failed to update duty cycle for %s", g_mosfet_map[chan].name);
    }
}

void mosfet_set_duty_percent(pwm_channel_t chan, float percentage) {
    if (chan >= PWM_CH_NUM) {
        ESP_LOGE(TAG, "Invalid channel index: %d", chan);
        return;
    }

    if (percentage < 0.0f) {
        ESP_LOGW(TAG, "%s requested duty lower than 0.0%% (%.2f%%). Clamping to 0.0%%", 
                 g_mosfet_map[chan].name, percentage);
        percentage = 0.0f;
    } else if (percentage > 100.0f) {
        ESP_LOGW(TAG, "%s requested duty higher than 100.0%% (%.2f%%). Clamping to 100.0%%", 
                 g_mosfet_map[chan].name, percentage);
        percentage = 100.0f;
    }

    uint32_t duty_raw = (uint32_t)((percentage / 100.0f) * MAX_DUTY_VALUE);
    mosfet_set_duty_raw(chan, duty_raw);
}

void mosfet_emergency_shutdown(void) {
    ESP_LOGE(TAG, "!!! EMERGENCY SHUTDOWN TRIGGERED !!! Shutting off all MOSFET outputs.");
    for (int i = 0; i < PWM_CH_NUM; i++) {
        ledc_set_duty(LEDC_LOW_SPEED_MODE, g_mosfet_map[i].channel, 0); // write to the registers
        ledc_update_duty(LEDC_LOW_SPEED_MODE, g_mosfet_map[i].channel); // then update the pwm channel
    }
}

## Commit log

2026-05-19 Add lower case handling
2026-05-20 Track .vscode directory
2026-05-20 Track sdkconfig
2026-05-21 Add TMC2209 driver files
2026-05-23 Write a temp motor test code in main
2026-07-29 Add a global configuration file for the printer
2026-07-31 feat(motion planner): Fix a typo in the ring buffer functions
    replaced the function parameters in the ring buffer functions where the ring
    buffer was sent as parameter of type PlannedMotion* to RingBuffer*.
    [motion_planner.h]
2026-08-01 feat(motion planner): add function prototypes
    forgot to add the function prototypes used in the motion planner implementation
    to the header file.
2026-08-01 feat(motion planner): initial junction velocity implementation
2026-08-01 feat(motion planner): add test file for junction velocity
2026-08-05 feat(motion planner): Add a test case of junc velocity to Makefile
2026-08-05 feat(motion planner): Complete test of junction velocity
2026-08-05 feat(motion planner): Edit conifg.h
    tested a few different feedrate speeds for the junction velocity
    calculation test.
2026-08-11 feat(motion planner): Add a test case for the finalize_motion_profiles() func
2026-08-12 Revert "Add home axes feature"
    This reverts commit 4b5a41ce62aea535030db102f5fb3017682ccb09.
    [motion_planner.h]
2026-08-20 Add forgotten function prototypes to motion planner header
2026-08-22 feat(tmc2209): Complete & test API for the TMC2209 motor driver
2026-08-26 Fix a few bugs with the RMT
    the axes are now moving, added a special case for the extruder.
    [config.h, step_generator.c, step_generator.h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]
2026-08-27 Add a test file for the endstops
2026-08-27 Add stuff for the endstops handling
2026-08-27 Fix the tripped axis index calculation
    [main.c]
2026-08-28 Add a feature to home axes function
    After homing successfuly, added commands to move the axes
    back a few mm away from the end stop switches.
2026-08-28 Add a motion type field to the motion struct
    now each motion has a field of motion type to differ between
    a homming and printing motion.
2026-08-28 Add a RMT API for ESP32-S3
2026-08-28 Initi commit of fans and heaters driver
2026-08-30 Initial commit of PID controller
2026-09-02 Fix a few bugs in Thermal
    [heaters_fans.c, heaters_fans.h, main.c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]
2026-09-02 Finish & Integrate Endstops
2026-09-22 Fix Z axis under-travel
    setup_tmc2209() and tmc2209_init_uart() were only ever called from
    the standalone driver test, never from main.c. Every TMC2209 driver
    (X/Y/Z/E) was booting on power-on/OTP default microstep resolution
    instead of the intended 1/16, a clean 4x mismatch — e.g. an 8mm Z
    move (lead screw, 8mm lead) only produced a quarter turn instead of
    a full one, even though the planner correctly computed 3200 steps
    for the move.
    - Call tmc2209_init_uart() + setup_tmc2209() for all four drivers in
    step_generator_task (main.c), before RMT channel init.
    - Fix GCONF in setup_tmc2209(): 0x00000040 only set pdn_disable
    (bit 6) for UART control, but never set mstep_reg_select (bit 7),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
    [main.c, tmc2209.c]
2026-09-22 Add axes movement clamping
2026-09-23 Fix homing hang when an endstop edge is missed
    - Check endstop level on each refill, in drain, and before approach
    - Clear queued step buffers on abort to stop overtravel
    - Increase Y back-off after homing to 5 mm
    [main.c]
2026-09-23 Make heaters work and add thermal safety
    - Init heater PWM at boot; fix swapped duty/channel args
    - Add default PID gains and PLA temperature limits
    - Keep thermal loop running; turn heaters off on abort
    - Add MINTEMP/MAXTEMP fault that stops the print
    - Make M109/M190 wait for target temperature
    - Stop dropping thermal commands;
    [motion_planner.h, thermal_task.c, thermal_task.h]
2026-09-23 Show live printer status on the OLED
    - Status screen: state, temps, XYZ, progress bar, print time
    - Refresh status screen at 2 Hz
    - Draw only from the UI task
2026-09-24 Adding PCB files & components
    [Copy of Header-Female-2.54_1x8.schdoc, FH2.54-09-22PZD.schdoc, Header-Female-2.54_1x6.schdoc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]
2026-09-25 Rename Schematic
    [3D-Printer.SchDoc, PCB_Project.PrjPcb, Sheet1.SchDoc]
2026-09-25 Ignore PCB History
2026-09-25 Directory cleanup
    [Copy of Header-Female-2.54_1x8.schdoc, FH2.54-09-22PZD.schdoc, Header-Female-2.54_1x6.schdoc]
2026-09-25 Add Buck Converter to Schematic
    [3D-Printer.SchDoc]
2026-09-26 Add more components the project's library
    [3D-Printer.SchDoc]
2026-09-26 Add updated components library
    [FinalProjectPcbLib.PcbLib, FinalProjectSchLib.SchLib]
2026-09-27 Creating pcb schematics
    [3D-Printer.SchDoc, PCB_Project.PrjPcb]
2026-09-27 Add PID autotune with saved gains and cleaner temperature readings
    - Forward M303 to the thermal task: E0 tunes the hotend, E-1 the bed
    - Make M303 block the G-code stream until the autotune finishes
    - Fix autotune math: missed crest peaks and doubled ultimate gain
    - Add 5 s minimum between autotune relay switches against sensor noise
    - Give each heater its own autotune timeout and cycle count
    - Save autotuned PID gains to NVS flash and load them at boot
    - Split runaway protection into heating-up and holding phases
    - Log the thermal fault shutdown once instead of every cycle
    - Show the autotune target on the display while tuning
    - Oversample both thermistors over one heater PWM period
    - Add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
    [adc.c, heaters_fans.c, heaters_fans.h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]
2026-09-27 Add decoupling capacitors for the TMC2209 24V
    [3D-Printer.SchDoc]
2026-09-27 Reorganize Schematics
    [3D-Printer.SchDoc, DaughterBoard.SchDoc, MotherBoard.SchDoc]
2026-09-27 Add Endstops + Daughterboard Connectors
    [DaughterBoard.SchDoc, MotherBoard.SchDoc, PCB_Project.PrjPcb]
2026-09-27 Fix planner crash on homing and add print test files
    - Raise Planner_Task stack to 8 KB (G28 overflowed 4 KB and rebooted the MCU)
    - Reduce Z back-off after homing from 3 mm to 0.5 mm
    - Add 10 mm cube, Z zero check and extruder check G-code files
    [main.c]
2026-09-28 Support G-code sliced with PrusaSlicer
    - Lexer: skip every space before a token (one space used to end the call without a token)
    and keep the upper-cased letter (it was overwritten with the raw character)
    - Parser: clear the command at the start of every line so no value carries over from the
    previous line; a T after G/M (e.g. "M104 S210 T0") is a tool index, not a command
    - Extruder mode like Marlin: G90/G91 also set the E mode, M82/M83 set it alone,
    and G28 keeps it (PrusaSlicer sends M83 before G28)
    - G92 also resets the step counters, so "G92 E0" no longer retracts everything extruded so far
    - M106 without S runs the fan at full speed, M107 turns it off
    - M400 waits until every que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
    [pyramid.3mf]
2026-09-28 Drive the part fan through an NPN switch at 100 Hz
    - Add PART_FAN_INVERTED (false): the fan is switched low-side by a single NPN, GPIO high = fan on
    - Lower the fan PWM from 25 kHz to 100 Hz: a 2-wire fan switched on its power line needs
    ms-long off-times, at 25 kHz its own input capacitor bridged them and it always ran at full speed
    - Add gcode/fan_test.gcode: full, half and low speed, then off, about 10 s each
2026-09-28 Make SD card streaming survive read errors
    - A missing card or file no longer returns from the streamer task (which rebooted the ESP32):
    it cancels the print and tries again on the next Start Print
    - On a read error, remount the card, reopen the file and continue from the start of the
    failed line; 5 tries per line, then stop the print with the heaters off
    - Check for a read error even when fgets returned part of a line, so a cut-off command
    (e.g. a lone "G") is never executed
    - At the end of the file, park the task instead of reading the closed file again
    - Skip lines longer than the buffer as a whole (PrusaSlicer's settings block at the end of
    the file); the rest of such a line used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
    [main.c, spi_sd.c]
2026-09-28 Zero Z 0.6 mm above the Z endstop and lift after homing
    - After the Z touch, back off 0.6 mm and set Z0 there (was 0.5 mm)
    - Then lift to Z5, so the nozzle doesn't stay at Z0 after G28
2026-09-28 Fix motion stalls and layer shifts
    - Step generator: count RMT TX-done completions in the ISR. Two banks finishing before the
    task woke merged into one notification, a completion was lost and the print froze mid-move
    - Step generator: start each block at the planner's entry speed and end it at its exit speed.
    Every block used to start from rest, so at joints the planner kept at speed the head stopped
    dead from full speed (lost steps, Y layer shifts)
    - Step generator: apply Austin's 0.676 first-step correction. Moves reached only ~68% of the
    planned speed and ~46% of the acceleration
    - Step generator: clamp step delays to the 15-bit RMT field, and wait for leftover
    transactions afte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
    [main.c, step_generator.c, step_generator.h]
2026-09-29 Finish Schematic Capture
    [DaughterBoard.SchDoc, FinalProjectPcbLib.PcbLib, FinalProjectSchLib.SchLib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]
2026-09-30 Continue working on the layout
    - Routed MCU, TMC2209 Motor Drivers, External Connectors.
    - Fans & MOSFETs.
    - Left to route the 24v and 3v3 lines
    [FinalProjectPcbLib.PcbLib, FinalProjectSchLib.SchLib, MotherBoard.SchDoc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]
2026-09-30 Finish routing daughterboard
    [DaughterBoard.SchDoc, MotherBoard.SchDoc, PCB.PcbDoc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]
2026-09-30 Fix DRC Violations
    [DaughterBoard.SchDoc, MotherBoard.SchDoc, PCB.PcbDoc]
2026-10-02 Finish PCB design
    [BOM.csv, DaughterBoard.SchDoc, MotherBoard.SchDoc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]
2026-10-04 Clean PCB directory
2026-10-05 Add Schematics & PCB Drawings
2026-10-06 Fix a typo
    - Fixed the inlet voltage value from 120VAC to 220VAC ~ 50Hz.
